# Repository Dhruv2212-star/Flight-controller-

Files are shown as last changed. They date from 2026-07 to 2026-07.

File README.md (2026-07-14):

# ASTRA FLIGHT CONTROLLER
The Astra Flight Controller is a custom-designed flight control board developed for multirotor unmanned aerial vehicles (UAVs). It is built around the STM32F411CEU6 microcontroller and the ICM-42688-P six-axis Inertial Measurement Unit (IMU), providing a compact, high-performance platform capable of running modern flight control firmware such as Betaflight, INAV, or customdeveloped firmware
1. **Main Features**
* STM32F411CEU6 ARM Cortex-M4 Microcontroller  
* ICM-42688-P 6-axis IMU  
* MP2359DJ High-Efficiency 5 V Buck Converter  
* AP2112K 3.3 V Low-Dropout Voltage Regulator  
* USB Type-C Interface  
* SWD Programming Header  
* XT30 Battery Input  
* Active Buzzer Driver Circuit  
* Status LED  
* External UART Expansion  
* Dedicated SPI Interface for the IMU  
* Compact PCB designed within a 100 mm × 100 mm manufacturing limit
  2. **Hardware Architecture**  
* Power Management  
* Processing Unit  
* Sensor System  
* Communication Interfaces  
* User Interface  
* Programming & Debugging  
* External Connections  
 3. **Hardware Modules Power Management**
Responsible for converting battery voltage into stable regulated voltages used by the board.
Major Components:
* XT30 Battery Connector  
* Resettable Fuse  
* MP2359DJ Buck Converter  
* AP2112K 3.3V Regulator Filtering Capacitors Outputs:  
 +5V Rail  
 +3.3V Rail  
4. **Processing Module**
The processing module is the "brain" of the flight controller. Main Component: STM32F411CEU6.
Responsibilities:  
* Reads sensor data  
* Executes flight control algorithms  
* Controls motors  
* Handles USB communication  
* Processes receiver input  
* Generates PWM/DShot signals    
* Controls LEDs and buzzer  
 5. **Sensor Module** 
The sensor subsystem provides real-time motion data.  
Main Sensor: ICM-42688-P.  
 
Measurements: 3-axis Accelerometer, 3-axis Gyroscope. Communication: SPI Interface.  
The IMU continuously measures angular velocity and acceleration  
**Power-Up Sequence**
*When battery power is applied, the following sequence occurs:*
Step 1: Battery voltage enters through the XT30 connector.  
Step 2: The resettable fuse protects the board from excessive current.  
Step 3: The MP2359DJ converts battery voltage into a regulated +5V supply.  
Step 4: The AP2112K converts +5V into +3.3V.  
Step 5: The STM32F411CEU6 receives stable power.   
Step 6: The crystal oscillator starts generating the system clock.  
Step 7: The microcontroller boots from Flash memory.  
Step 8: The SPI interface initializes the ICM-42688-P.  
Step 9: Sensors begin transmitting motion data.  
Step 10: the flight controller enters normal operating mode 

------------------------------------------------------------------------------------------------------------------------------------------

**Clock Generation**
The STM32F411CEU6 uses an external crystal oscillator for accurate timing. The external crystal provides stable CPU clock, accurate USB timing, reliable SPI communication, and consistent sensor sampling. Proper placement of the crystal and its load capacitors is essential for reliable operation.  

**power system**
Why Two Regulators?  
Using a single linear regulator directly from the battery would result in excessive heat generation, especially at higher input voltages. Instead, the Astra Flight Controller uses a two-stage regulation    
approach:  
* MP2359DJ Buck Converter — efficiently reduces battery voltage to 5 V.  
* AP2112K LDO — produces a clean and stable 3.3 V output with minimal electrical  
noise. This combination provides both efficiency and stable operation.  

**STM32F411CEU6 Microcontroller**
The STM32F411CEU6 is the primary processing unit of the Astra Flight Controller. It executes the flight control firmware, processes sensor data, generates motor outputs, and manages all communication interfaces.
Role-   
The STM32 reads IMU data through SPI, executes flight control algorithms, generates ESC outputs, monitors battery voltage, controls the LED and buzzer, manages USB communication, and supports firmware programming through SWD.  

## ICM-42688-P Inertial Measurement Unit (IMU)  
 *Introduction*  
The ICM-42688-P is the primary motion sensing device used in the Astra Flight Controller. It integrates a 3-axis accelerometer and a 3-axis gyroscope in a compact LGA package. The sensor continuously measures aircraft motion and sends this data to the STM32F411CEU6 through the SPI interface for attitude estimation and flight stabilization.    
**Why the ICM-42688-P was Selected?**  
The sensor was selected because of its excellent gyroscope noise performance, high sampling rate, low latency, low power consumption, compact size, and broad support in modern flight-control firmware such as Betaflight and INAV.  
Main Specifications:-  
* Device- ICM-42688-P  
* Sensor Type- 6-Axis IMU  
* Accelerometer- 3-Axis MEMS  
* Gyroscope- 3-Axis MEMS  
* Operating Voltage- 1.71–3.6 V  
* Communication- SPI / I²C  
* Max SPI Clock Up to 24 MHz  
* Operating Temp −40°C to +85°C    
**Working Principle**  
The accelerometer measures linear acceleration along the X, Y, and Z axes, while the gyroscope  
measures angular velocity about the same axes. Together they provide six degrees of freedom (6-DoF), allowing the firmware to estimate   the aircraft's orientation using sensor-fusion algorithms.  
**Hardware Integration**  
The IMU operates from the regulated 3.3 V rail. VDD and VDDIO are connected to 3.3 V, while the GND pins connect directly to the ground plane. Local decoupling capacitors are placed close to the power pins to reduce supply noise and improve stability.    
**SPI Communication**  
Communication with the STM32F411CEU6 takes place over SPI using SCK, MOSI, MISO, and CS. SPI was selected instead of I²C because it offers higher bandwidth, lower latency, and improved reliability in electrically noisy environments.  
**Interrupt Output**
The interrupt pin notifies the STM32 whenever new sensor data is available, reducing processor workload and improving the timing of the flight-control loop.  

The IMU continuously measures aircraft motion, sends accelerometer and gyroscope data to the STM32 through SPI, and the firmware processes this information to estimate attitude and generate motor control outputs.  

## USB Type-C Interface

*Introduction*  
The USB Type-C interface serves as one of the primary communication and power interfaces of the Astra Flight Controller. It provides firmware flashing, debugging, configuration, diagnostics and  
development power.  
USB Type-C offers reversible insertion, improved durability, better current capability and long-term compatibility. The design uses the USB 2.0 Full-Speed interface connected directly to the STM32F411CEU6.   

**Purpose**
Firmware upload, configuration using Betaflight/INAV/STM32CubeProgrammer, debugging through serial communication, and powering the board during development without a LiPo battery  
**Advantages**  
Reversible connector, stronger mechanical retention, higher current capability and modern industrystandard compatibility.  
**USB Connector**
| Pin | Function |  
| VBUS | +5V |  
| GND | Ground |  
| D+ | USB Data Positive |  
| D- | USB Data Negative |  
| CC1 | Configuration Channel 1 |  
| CC2 | Configuration Channel 2 |  
| Shield | Connector Shield |  

**Data Communication**
USB Full-Speed uses the D+ and D− differential pair. Route them together with matched lengths, minimal vias, constant spacing, no sharp bends and a continuous ground plane. The STM32F411CEU6 supports USB 2.0 Full-Speed (12 Mbps), sufficient for firmware updates and configuration  
##  XT30 Battery Connector
The XT30 connector is the primary battery input. Battery voltage enters the board through the XT30 connector, passes through the resettable fuse and protection circuitry, and then feeds the MP2359DJ buck converter. Wide copper traces are used to carry battery current and minimise voltage drop.  
## ESC Connections
Motor control signals generated by the STM32 are routed to the ESC outputs. These connections carry logiclevel control signals only; motor power is supplied separately by the battery through the ESCs.   
#  Indicators and User Interface
**Overview**  
The Astra Flight Controller includes a status LED, a TL3342 push button and an active buzzer. These devices provide visual, audible and manual interaction during development, testing and flight operation.  
**Status LED**
The STM32 controls the LED to indicate power, boot status, firmware activity, calibration, arming state and error conditions.  
**Push Button**
The TL3342 tactile switch can be used for boot mode selection, firmware recovery, calibration and user-defined functions through a GPIO input.  
**Active Buzzer**
The active buzzer provides audible feedback including startup, arming, low-battery and fault indications. It requires only an on/off control signal from the STM32.  
## Component Placement Strategy
1. Microcontroller Placement  
The STM32F411CEU6 is positioned near the center of the PCB. This location minimizes the average distance between the MCU and all connected peripherals, resulting in shorter SPI traces, shorter USB connections, reduced propagation delay, easier routing, and improved signal integrity. The exposed thermal pad beneath the MCU is connected directly to the ground plane for both thermal dissipation and electrical grounding.  
2. IMU Placement  
The ICM-42688-P is the most sensitive component on the board. To maximize Measurement accuracy, it is placed close to the center of the PCB, kept away from the MP2359DJ buck converter and inductor, and highcurrent traces are not routed beneath the sensor. A continuous ground plane is maintained underneath the device, and the sensor orientation matches the coordinate system  
expected by the firmware.  
Proper placement reduces electrical interference and vibration-induced measurement errors  
**Power Section Placement**
The power conversion circuitry is grouped together near the battery input. This includes:  
* XT30 connector.  
* Resettable fuse.  
* Protection diode.  
* MP2359DJ buck converter.  
* 4.7 µH Bourns SRP5030TA-4R7M inductor.  
* Input and output capacitors.  
* AP2112K voltage regulator.  
## Power Supply Design
The Astra Flight Controller is designed to operate directly from a 2S to 6S Lithium Polymer (LiPo) battery, meaning the input voltage can vary from approximately 7.4 V to 25.2 V. To achieve stable regulation, the Astra Flight Controller uses a two-stage power architecture: the MP2359DJ synchronous buck converter generates a regulated 5 V supply from the battery, and the AP2112K Low Dropout (LDO) regulator generates a clean 3.3 V supply from the 5 V raiL  

 Power Flow
2S–6S LiPo Battery  
|  
XT30 Battery Connector  
|  
Resettable Fuse (F1)  
|  
TVS / Reverse Protection  
|  
MP2359DJ Buck Converter — +5 V Rail  
|  
AP2112K LDO Regulator — +3.3 V Rail  
|  
STM32F411 
|  
ICM-42688  
##  Resettable Fuse (F1)
Immediately after the XT30 connector, the input passes through a resettable polyfuse (PTC), which protects the PCB from excessive current caused by short circuits, incorrect wiring, component failures, or assembly mistakes. Unlike a traditional fuse, the polyfuse automatically resets after the fault is removed and the device cools down.  

## MP2359DJ Buck Converter
1. Why a Buck Converter?
A linear regulator would dissipate the voltage difference between the battery and the output as heat. Converting 25.2 V from a fully charged 6S battery directly to 5 V using a linear regulator would result in excessive power loss and unacceptable temperatures. A switching buck converter solves this problem by rapidly switching the input voltage through an inductor and filtering the output,
achieving efficiencies typically above 85–90%.  
2. MP2359DJ Features  
* Wide input voltage range.  
* High conversion efficiency.  
* Integrated MOSFETs.  
* Compact package.  
* High switching frequency.  
* Internal protection features.  
* Minimal external components.  
3. Operating Principle  
The MP2359DJ is a synchronous step-down (buck) switching regulator. Its operation consists of four basic stages: the internal MOSFET switches ON allowing current to flow into the inductor; energy is stored in the magnetic field of the inductor; the MOSFET switches OFF; and the inductor releases stored energy through the output filter, maintaining a continuous output voltage. This cycle repeats
hundreds of thousands of times per second.
External Components-- 
● Input capacitor.
● Output capacitor.
● Bootstrap capacitor.
● Schottky protection diode (where applicable).
● Feedback resistor network.
● 4.7 µH power inductor

 # Manufacturing 
The PCB is designed to be compatible with standard manufacturing services such as JLCPCB while
remaining within the 100 mm × 100 mm board size 

# Screenshots
*Schematic*
Flight controler_page-0001 (1)
*PCB tracing* 
Screenshot (255)
*3D view*
Screenshot (254)
 
 * Note-- the firmware needs to be programed according to the use, hence cannot be pre-programed

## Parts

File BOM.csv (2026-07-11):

Ref | Qty | Value/Description | Manufacturer Part | Package | Footprint
U1 | 1 | 6-Axis IMU | ICM-42688-P | LGA-14 | Package_LGA:LGA-14_2.5x3mm_P0.5mm
U2 | 1 | 3.3V LDO | AP2112K-3.3 | SOT-23-5 | Package_TO_SOT_SMD:SOT-23-5
U3 | 1 | Buck Regulator | MP2359DJ | TSOT-23-6 | Package_TO_SOT_SMD:TSOT-23-6
U4 | 1 | MCU | STM32F411CEU6 | LQFP-48 | Package_QFP:LQFP-48_7x7mm_P0.5mm
Q1 | 1 | MMBT2222A | MMBT2222A | SOT-23 | Package_TO_SOT_SMD:SOT-23
Y1 | 1 | 8MHz Crystal | Generic | 3225 | Crystal:Crystal_SMD_3225-4Pin_3.2x2.5mm
L1 | 1 | 4.7uH Shielded Inductor | Bourns SRP5030TA-4R7M | SRP5030 | Inductor_SMD:L_Bourns_SRP5030TA
D1 | 1 | Green LED | Generic | 0603 | LED_SMD:LED_0603_1608Metric
D2 | 1 | Blue LED | Generic | 0603 | LED_SMD:LED_0603_1608Metric
D3 | 1 | SS14 | SS14 | SMA | Diode_SMD:D_SMA
D4 | 1 | SMBJ26CA | SMBJ26CA | SMB | Diode_SMD:D_SMB
F1 | 1 | Polyfuse | Bourns MF-MSMF200/16X-2 | 1812 | Fuse:Fuse_1812_4532Metric
SW1 | 1 | Reset Switch | TL3342 | SMD | Button_Switch_SMD:SW_SPST_TL3342
BZ1 | 1 | Active Buzzer | Generic | TH | Buzzer_Beeper:Buzzer_12x9.5RM7.6
J1 | 1 | USB-C | HRO TYPE-C-31-M-12 | USB-C | Connector_USB:USB_C_Receptacle_HRO_TYPE-C-31-M-12
J2 | 1 | SWD Header | Generic | 2.54mm | Connector_PinHeader_2.54mm:PinHeader_2x03_P2.54mm_Vertical
J3 | 1 | Receiver Header | Generic | 2.54mm | Connector_PinHeader_2.54mm:PinHeader_1x04_P2.54mm_Vertical
J4 | 1 | ESC Header | Generic | 2.54mm | Connector_PinHeader_2.54mm:PinHeader_1x08_P2.54mm_Vertical
J5 | 1 | Battery Header | Generic | 2.54mm | Connector_PinHeader_2.54mm:PinHeader_1x02_P2.54mm_Vertical
R1 | 1 | 22Ω | Generic 1% | 0603 | Resistor_SMD:R_0603_1608Metric
R2 | 1 | 22Ω | Generic 1% | 0603 | Resistor_SMD:R_0603_1608Metric
R3 | 1 | 5.1kΩ | Generic 1% | 0603 | Resistor_SMD:R_0603_1608Metric
R4 | 1 | 5.1kΩ | Generic 1% | 0603 | Resistor_SMD:R_0603_1608Metric
R5 | 1 | 1MΩ | Generic 1% | 0603 | Resistor_SMD:R_0603_1608Metric
R6 | 1 | 10kΩ | Generic 1% | 0603 | Resistor_SMD:R_0603_1608Metric
R7 | 1 | 330Ω | Generic 1% | 0603 | Resistor_SMD:R_0603_1608Metric
R8 | 1 | 330Ω | Generic 1% | 0603 | Resistor_SMD:R_0603_1608Metric
R9 | 1 | 10kΩ | Generic 1% | 0603 | Resistor_SMD:R_0603_1608Metric
R10 | 1 | 1kΩ | Generic 1% | 0603 | Resistor_SMD:R_0603_1608Metric
R11 | 1 | 49.9kΩ | Generic 1% | 0603 | Resistor_SMD:R_0603_1608Metric
R12 | 1 | 9.53kΩ | Generic 1% | 0603 | Resistor_SMD:R_0603_1608Metric
R13 | 1 | 180kΩ | Generic 1% | 0603 | Resistor_SMD:R_0603_1608Metric
R14 | 1 | 27kΩ | Generic 1% | 0603 | Resistor_SMD:R_0603_1608Metric
C1 | 1 | 2.2uF 10V | Generic | 0603 | Capacitor_SMD:C_0603_1608Metric
C2 | 1 | 100nF 16V | Generic | 0603 | Capacitor_SMD:C_0603_1608Metric
C3 | 1 | 100nF 16V | Generic | 0603 | Capacitor_SMD:C_0603_1608Metric
C4 | 1 | 100nF 16V | Generic | 0603 | Capacitor_SMD:C_0603_1608Metric
C5 | 1 | 18pF 50V | Generic | 0603 | Capacitor_SMD:C_0603_1608Metric
C6 | 1 | 18pF 50V | Generic | 0603 | Capacitor_SMD:C_0603_1608Metric
C7 | 1 | 100nF 16V | Generic | 0603 | Capacitor_SMD:C_0603_1608Metric
C8 | 1 | 22uF 35V | Generic | 1206 | Capacitor_SMD:C_1206_3216Metric
C9 | 1 | 22uF 10V | Generic | 1206 | Capacitor_SMD:C_1206_3216Metric
C10 | 1 | 100nF 50V | Generic | 0603 | Capacitor_SMD:C_0603_1608Metric
C11 | 1 | 100nF 16V | Generic | 0603 | Capacitor_SMD:C_0603_1608Metric
C13 | 1 | 1uF 10V | Generic | 0603 | Capacitor_SMD:C_0603_1608Metric
C14 | 1 | 1uF 10V | Generic | 0603 | Capacitor_SMD:C_0603_1608Metric

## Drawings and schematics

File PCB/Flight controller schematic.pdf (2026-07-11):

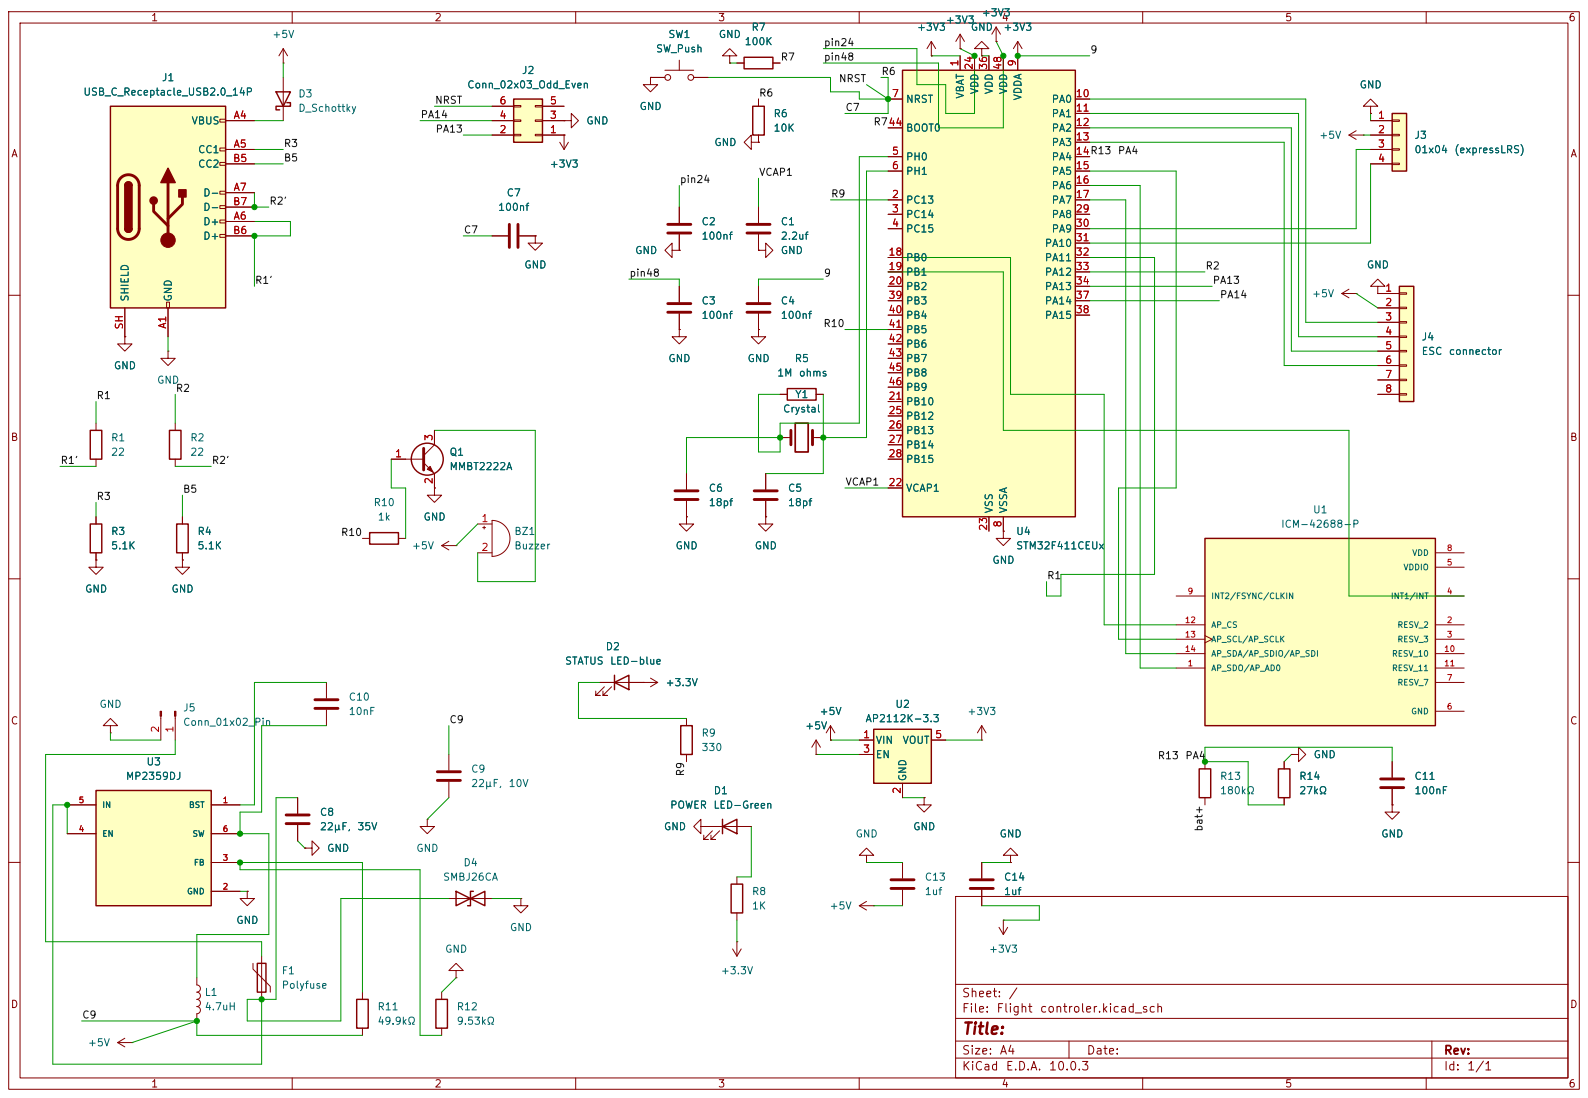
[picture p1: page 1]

D1 POWER LED-Green GND

Size: A4 | Rev:
KiCad E.D.A. 10.0.3 | Id: 1/1

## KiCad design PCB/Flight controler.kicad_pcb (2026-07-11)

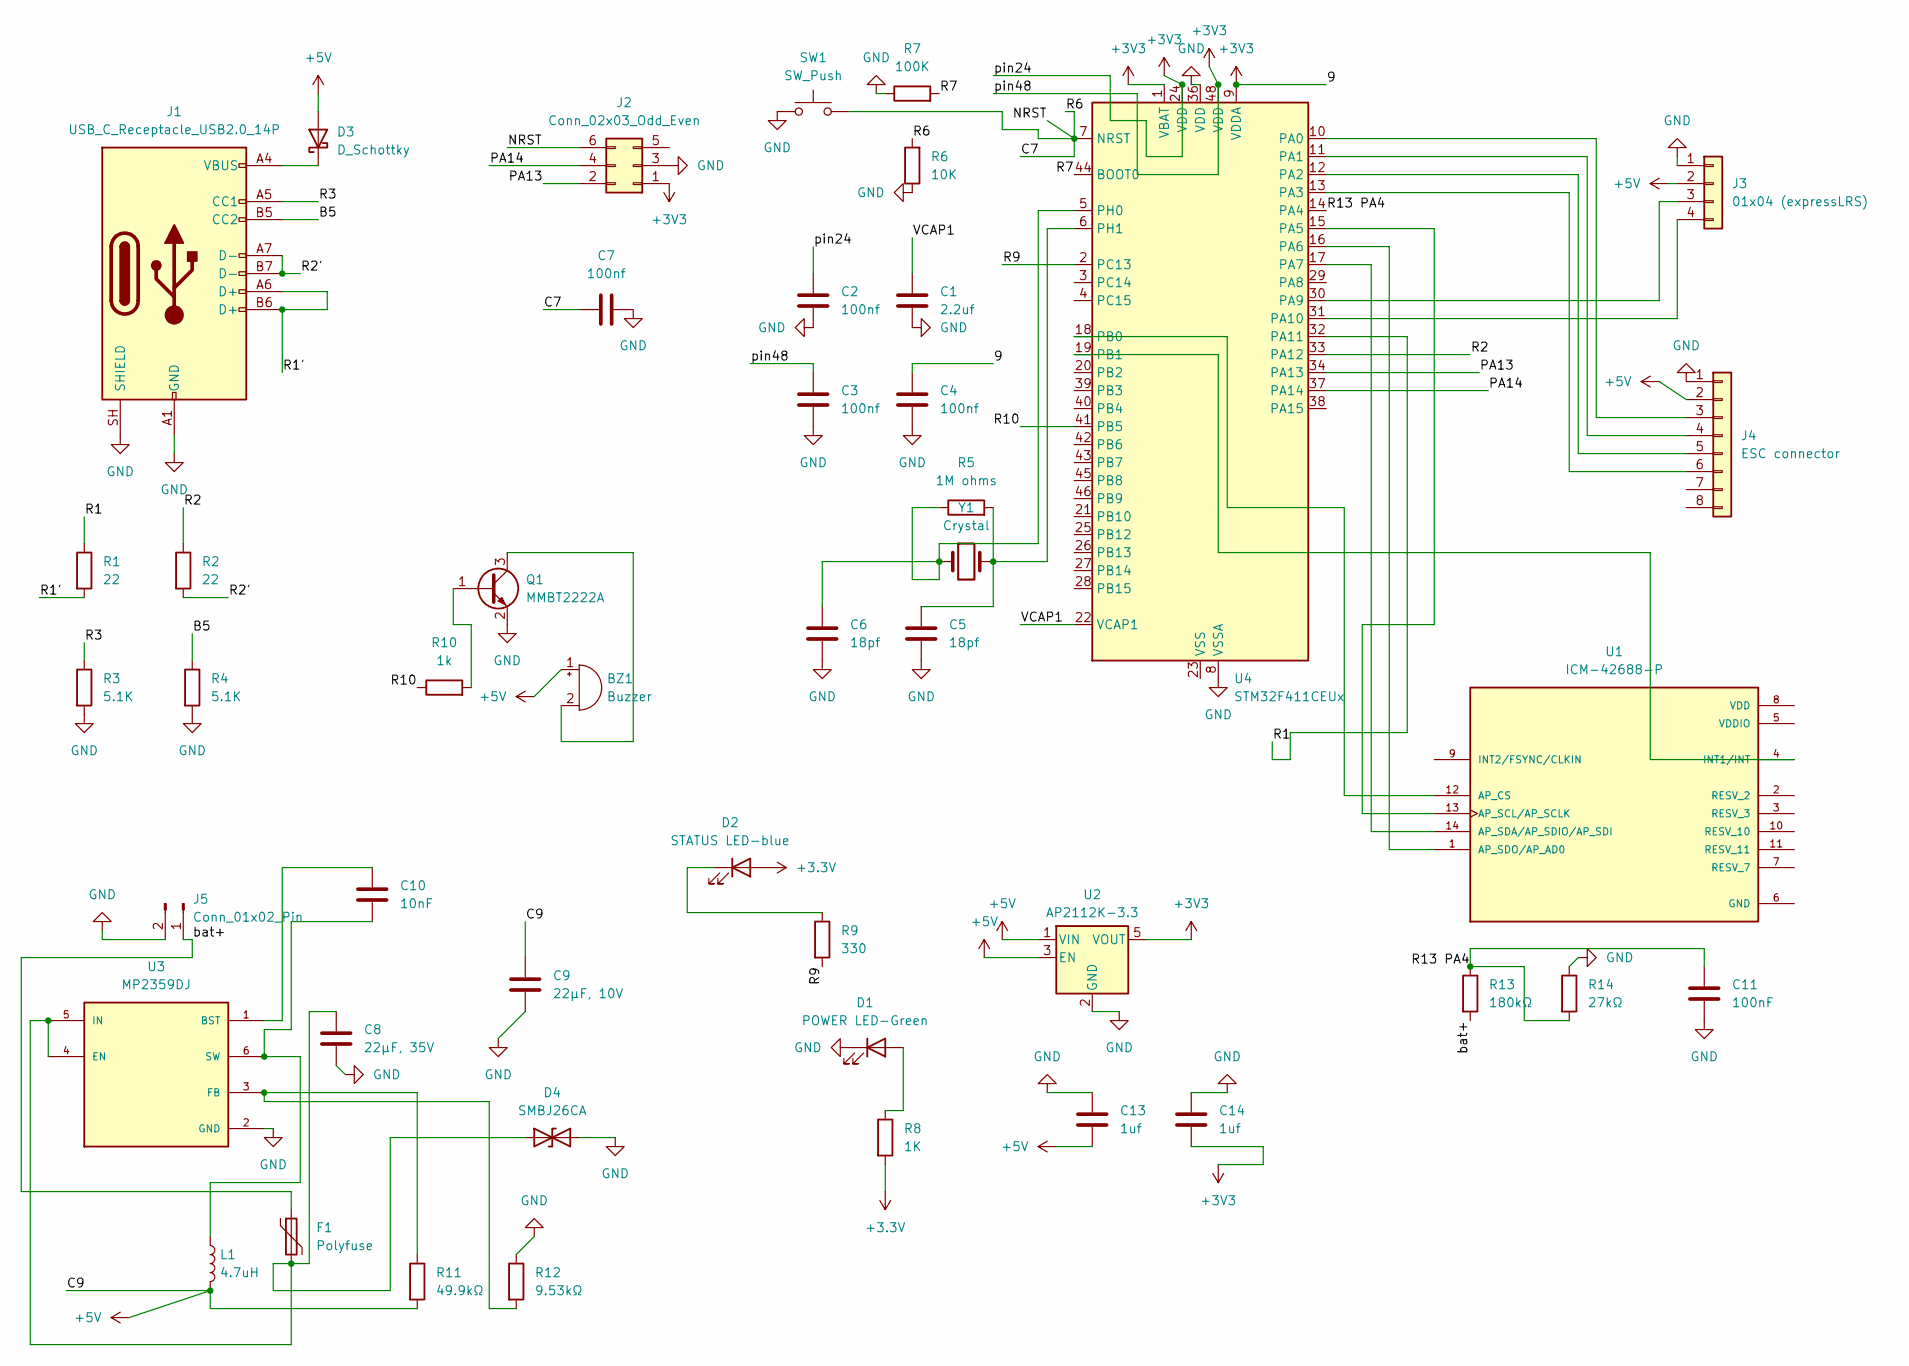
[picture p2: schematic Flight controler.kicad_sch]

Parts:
BZ1: Buzzer; Buzzer_12x9.5RM7.6
C1: 2.2uf; C_0603_1608Metric
C2, C3, C4, C7: 100nf; C_0603_1608Metric
C5, C6: 18pf; C_0603_1608Metric
C8: 22µF, 35V; C_1206_3216Metric
C9: 22µF, 10V; C_1206_3216Metric
C10: 10nF; C_0603_1608Metric
C11: 100nF; C_0603_1608Metric
C13, C14: 1uf; C_0603_1608Metric
D1: POWER LED-Green; LED_0603_1608Metric
D2: STATUS LED-blue; LED_0603_1608Metric
D3: D_Schottky; D_SMA
D4: SMBJ26CA; D_SMB
F1: Polyfuse; Fuse_1812_4532Metric
J1: USB_C_Receptacle_USB2.0_14P; USB_C_Receptacle_HRO_TYPE-C-31-M-12
J2: Conn_02x03_Odd_Even; PinHeader_2x03_P2.54mm_Vertical
J3: 01x04 (expressLRS); PinHeader_1x04_P2.54mm_Vertical
J4: ESC connector; PinHeader_1x08_P2.54mm_Vertical
J5: Conn_01x02_Pin; PinHeader_1x02_P2.54mm_Vertical
L1: 4.7uH; L_6.3x6.3_H3
Q1: MMBT2222A; TSOT-23-6
R1, R2: 22; R_0603_1608Metric
R3, R4: 5.1K; R_0603_1608Metric
R5: 1M ohms; R_0603_1608Metric
R6: 10K; R_0603_1608Metric
R7: 100K; R_0603_1608Metric
R8: 1K; R_0603_1608Metric
R9: 330; R_0603_1608Metric
R10: 1k; R_0603_1608Metric
R11: 49.9kΩ; R_0603_1608Metric
R12: 9.53kΩ; R_0603_1608Metric
R13: 180kΩ; R_0603_1608Metric
R14: 27kΩ; R_0603_1608Metric
SW1: SW_Push; SW_SPST_TL3342
U1: ICM-42688-P; PQFN50P300X250X97-14N; PARTREV 1.2
U2: AP2112K-3.3; SOT-23-5
U3: MP2359DJ; TSOT-23-6; PARTREV 1.21
U4: STM32F411CEUx; QFN-48-1EP_7x7mm_P0.5mm_EP5.6x5.6mm
Y1: Crystal; Crystal_SMD_3225-4Pin_3.2x2.5mm

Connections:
+3.3V: D2.2 (A), R8.2
+3V3: C2.1, C3.1, C4.1, C14.2, J2.1, U2.5 (VOUT), U4.1 (VBAT), U4.9 (VDDA), U4.24 (VDD), U4.48 (VDD)
+5V: BZ1.1 (+), C9.1, C13.2, D3.2 (A), J3.2, J4.2, L1.2, R11.2, U2.1 (VIN), U2.3 (EN)
/B5: J1.B5 (CC2), R4.1
/C7: C7.1, J2.6, R6.2, SW1.2, U4.7 (NRST)
/PA13: J2.2, U4.34 (PA13)
/PA14: J2.4, U4.37 (PA14)
/R1: R1.1, U4.32 (PA11)
/R1': J1.A6 (D+), J1.B6 (D+), R1.2
/R2: R2.1, U4.33 (PA12)
/R2': J1.A7 (D-), J1.B7 (D-), R2.2
/R3: J1.A5 (CC1), R3.1
/R7: R7.2, U4.44 (BOOT0)
/R9: R9.2, U4.2 (PC13)
/R10: R10.1, U4.41 (PB5)
/R13 PA4: C11.1, R13.1, R14.2, U4.14 (PA4)
/VCAP1: C1.1, U4.22 (VCAP1)
/bat+: F1.1, J5.1, R13.2
GND: C1.2, C2.2, C3.2, C4.2, C5.2, C6.2, C7.2, C8.2, C9.2, C11.2, C13.1, C14.1, D1.1 (K), D4.2 (A2), J1.A1 (GND), J1.A12 (GND), J1.B1 (GND), J1.B12 (GND), J1.SH (SHIELD), J2.3, J3.1, J4.1, J5.2, Q1.2 (E), R3.2, R4.2, R6.1, R7.1, R12.1, R14.1, SW1.1, U2.2 (GND), U3.2 (GND), U4.8 (VSSA), U4.36 (VDD)
unnamed: BZ1.2 (-), Q1.3 (C)
unnamed: D1.2 (A), R8.1
unnamed: D2.1 (K), R9.1
unnamed: D3.1 (K), J1.A4 (VBUS), J1.A9 (VBUS), J1.B4 (VBUS), J1.B9 (VBUS)
unnamed: C8.1, D4.1 (A1), F1.2, U3.4 (EN), U3.5 (IN)
unnamed: J3.3, U4.30 (PA9)
unnamed: J3.4, U4.31 (PA10)
unnamed: J4.3, U4.10 (PA0)
unnamed: J4.4, U4.11 (PA1)
unnamed: J4.5, U4.12 (PA2)
unnamed: J4.6, U4.13 (PA3)
unnamed: Q1.1 (B), R10.2
unnamed: U1.12 (AP_CS), U4.18 (PB0)
unnamed: U1.13 (AP_SCL/AP_SCLK), U4.15 (PA5)
unnamed: U1.14 (AP_SDA/AP_SDIO/AP_SDI), U4.17 (PA7)
unnamed: U1.1 (AP_SDO/AP_AD0), U4.16 (PA6)
unnamed: U1.4 (INT1/INT), U4.19 (PB1)
unnamed: C10.1, U3.1 (BST)
unnamed: R11.1, R12.2, U3.3 (FB)
unnamed: C10.2, L1.1, U3.6 (SW)
unnamed: C6.1, R5.1, U4.5 (PH0), Y1.1
unnamed: C5.1, R5.2, U4.6 (PH1), Y1.2
unnamed: U4.23 (VSS), U4.35 (VSS), U4.47 (VSS), U4.49 (VSS)

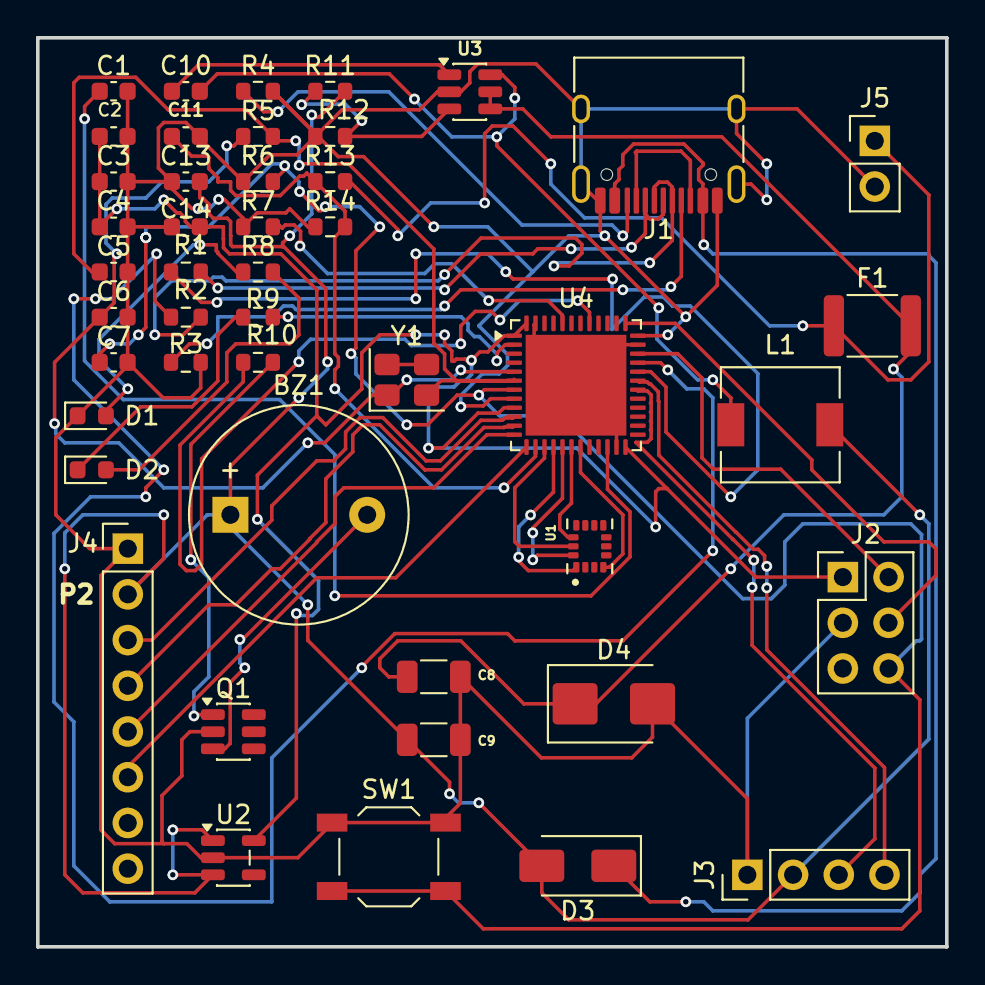
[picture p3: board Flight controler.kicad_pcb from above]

Board: 2 copper layers, 50.5 x 50.5 mm, 46 parts (0 on the bottom side), 42 nets.

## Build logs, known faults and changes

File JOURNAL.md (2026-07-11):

# schematic 
https://lapse.hackclub.com/timelapse/As67MyGgbrsy- research and adding all the necessary components  
https://lapse.hackclub.com/timelapse/pfVKS3YQiEa1- making all the block systems and making the final connections  
https://lapse.hackclub.com/timelapse/KVyzKA2z3cqI- Added powerlines (battery connections and also utlised one of the gpio pins for battery data  
https://lapse.hackclub.com/timelapse/k_mX-gwa9zRS- searched for parts for footprints  
https://lapse.hackclub.com/timelapse/GKvWLAXhc2rL- Finished the final part, PCB tracin  
## Initial research on the parts to use and the modules avalable and the datasheets | 1 hour 
## Made the STM chip->IMU connetions | 35 mins  

## Made the USB connections | 5mins   

Screenshot (245)
## Power Suply | 10mins

Screenshot (248)
## STM powering | 15mins 

Screenshot (249)
## Crystal connections | 9mins  

Screenshot (250)
## finished the 2x3 pinheader | 15mins  


## made the reset and boot circuit | 15mins 


## finished setting up the Power LED nad the Status LED **5mins**   

Screenshot (252)
## added buzzer | 10mins 


## made changes to the MP2359J module and added power lines | 1 hour 30 mins


## Research and adding terminal for battery and created a path to measure battery voltage | 1 hour 30 mins 



## searched for parts online and added relative footprints | 1 hour 8 mins 


## PCB routing | 3 hours 
Screenshot (255)
Screenshot (256)

## Note- it took me this much time because i had to constantly go back and fouth into the data sheet for details as this was my first project that i made that was a bit on higher difficulty as i had to go through data sheets of multiple components  
*research time*- 14 hours

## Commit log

2026-07-10 Update JOURNAL.md with new connections and times
    Added details about USB connections, power supply, and STEM powering with respective time spent.
2026-07-10 Added reset & boot circuit and 2x3 headers
    Added new entries for finished pinheader and circuits.
2026-07-10 Added buzzer and the lapse links
    Updated JOURNAL.md with additional project details, including new sections for USB connections, power supply, and added components like a buzzer and LEDs. Included images and time estimates for each task.
2026-07-10 Added powerlines to the schematic and utilised one more GPIO pin for Baterry data
    Updated the JOURNAL.md to improve formatting and add new entries for various connections and components.
2026-07-10 Add schematic link to README
2026-07-11 New schematic
2026-07-11 added journal entry for schematic update
    Added details about changes made to the MP2359J module and included images.
2026-07-11 Added a new entry for searching parts online and updating footprints in the journal
2026-07-11 added PCB schematic
    [Flight controler.kicad_sch]
2026-07-11 updated the schematic pics
2026-07-11 PCB tracing
2026-07-11 Finished the PCB tracing and arrangement
    [Flight controler.kicad_pcb, Flight controler.kicad_sch]
2026-07-13 PCB tracing and 3D view
    Updated README to include final PCB tracing and 3D view images. Clarified AI usage in data compilation.
2026-07-13 Gerber file
2026-07-13 updated gerber & manual
2026-07-14 Flight Controller details
    Expanded the README to include detailed information about the Astra Flight Controller, its features, hardware architecture, power management, and components.
2026-07-14 Refactor power-up sequence for clarity
    Removed redundant steps from the power-up sequence in the README.
2026-07-14 Improve USB connector table in README
    Updated USB connector table formatting for clarity.
